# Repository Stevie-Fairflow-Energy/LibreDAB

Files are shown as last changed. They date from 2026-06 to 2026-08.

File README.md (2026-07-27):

# LibreDAB
An open source bi-directional Dual Active Bridge converter for connecting a Sodium Ion Battery to a 400 V DC link
Taking strong inspiration from the OwnTech microinverter: https://github.com/owntech-foundation/micro-inverter/

  Development Stage - Planning - Design has not started.

- **Manifesto**
	- The project goals are to:
		- Develop an open source bi-directional Dual Active Bridge converter for connecting a Sodium Ion Battery to a 400 V DC link.
		- Make the design repairable in itself.
		- Make the design a useful module within the context of solar PV, batteries and inverters. (e.g. a portable power station)
- **Open, for everyone, forever**
	- This project welcomes community input. With strong links to the OwnTech foundation and Fairflow Energy.
	- The collective work generated is meant to remain open.
	- Design files are made with open source software - Namely KiCAD.
- **Specifications**

Category | Requirement | Notes 
:---|:---|:---
Battery chemistry | Sodium Ion | New battery technology with abundant raw material availability 
Battery voltage range | 23.8 V - 58.8 V | 14 Series Cells of ~1.7 V to 4.2 V per cell. This enables compatibility with LibreSolar BMS C1 which sets a maximum voltage of 60 V. (https://github.com/LibreSolar/bms-c1) 
Nominal Battery Voltage | 42 V | Based on 3 V per cell 
Nominal Battery Current | 20 A | At 42 V and 800 W power transfer to DC link 
Peak Battery Current | 35.3 A | At 23.8 V and 800 W power transfer to DC link 
DC Link Voltage | 400 V | Based on a 230 V AC inverter 
Nominal DC link current | 2 A | 
Rated DC link Power | 800 W | Sufficient for a plug-in solar and storage application 
Efficiency | >95% | Target at nominal conditions 
Size | Target 70 mm x 280 mm PCB footprint | Similar size to 14 x 18650 cells next to each other 

- **Repairability**
	- Golden rules:
		- Components only placed on a single side of the PCB to allow simple rework
		- Components should be handle-able with standard tweezers (no smaller than 0402 packages)
		- Physical mounting is done with screws or other re-mountable arrangements
		- No invasive potting to enable inspection and service
		- There shall be test points available for all major power and control nets
	- Preferences:
		- Use of pin-compatible parts. e.g. a common footprint that has multiple options from different manufacturers to meet the same function
		- Minimise the number of different passive components used. e.g. parallel or series common components on the BOM where possible.
	- Notes:
		- Long-term relevance will be maintained at a whole module level. I.e. This DAB should be maintained and updated as a functional block when components used become unavailable. The physical size, mounting arrangements and connections should be maintained in future revisions.
	  
- **Control**
	- LibreDAB shall follow a bi-directional power reference. Therefore it needs to know voltage and current on both sides of the converter.
	- The reference can be delivered either as an analogue voltage signal or via serial.
	- LibreDAB shall provide a "No Error" indication, the absence of that indication should be read as an error.
   
- **Key Component Selections**
	- <100 V switch
		- TI LMG5200MOFR - 80 V, 10 A half bridge with driver
		- EPC2152 - 80 V, 15 A half bridge with driver
		- EPC23102 - 100 V, 35 A half bridge with driver - https://epc-co.com/epc/products/gan-fets-and-ics/epc23102
		- **Siliup SP010N01BGHTO 100 V 370A TOLL-8L MOSFET  https://www.lcsc.com/product-detail/C22385350.html?s_z=n_q_SP010N01BGHTO plus TI Driver UCC27211DDAR https://www.lcsc.com/product-detail/C141980.html?s_z=n_q_UCC27211DDAR**
	- . >500 V switch
		- **TI LMG2652 GaN Integrated Half Bridge and driver** 650 V, 140 mOhm - https://www.ti.com/product/LMG2652
		- Tokmas CID12N65D(TOKMAS) GaN single switch with integrated driver 650 V,  - 140 mOhm https://www.lcsc.com/product-detail/C21547657.html?s_z=n_q_C21547657&globalKeyword=C21547657
	- Controller
		- OwnTech SPIN https://www.owntech.org/spin-2/

- **Expected PCB Stackup**
	- 4 Layer FR4 insulated PCB with the following layer assignments:
		- Sig / Power 2oz
		- In.1 reference 2oz GND plane
		- Core
		- In.2 reference 2oz GND plane
		- Sig / Power 2oz
 - **Prototyping Status**
    - Prototype LV Bridge module ready for review.
    - Design in KiCAD 9.0.7
    - The LV Bridge module is a functional LV H bridge inverter to interface between the battery / BMS and the High Frequency DAB transformer. The prototype module has gate drivers on board as well as DC voltage and current measurements. The control interfaces for the gate drive signals, voltage and current measurements and 12 V and 5 V power supplies should be connected using 2.54 mm pin headers.
        - 4 Layer FR4 insulated PCB with the following layer assignments, with via stitching for power nets to maximise use of the PCB copper for power transfer:
		  - Sig / Power 1oz
		  - In.1 reference 0.5oz GND plane
		  - Core
		  - In.2 reference 0.5oz GND plane
		  - Sig / Power 1oz
    - Specifications for LV Bridge prototype module:
    
Category | Requirement | Notes 
:---|:---|:---
Battery voltage range | 23.8 V - 58.8 V | 14 Series Cells of ~1.7 V to 4.2 V per cell. This enables compatibility with LibreSolar BMS C1 which sets a maximum voltage of 60 V. (https://github.com/LibreSolar/bms-c1) 
Nominal Battery Voltage | 42 V | Based on 3 V per cell 
Nominal Battery Current | 20 A | At 42 V and 800 W power transfer to DC link 
Peak Battery Current | 35.3 A | At 23.8 V and 800 W power transfer to DC link 
Efficiency | >97% | Target at nominal conditions 
Size | 92 mm x 92 mm PCB  | Sized to mount 92 mm fan

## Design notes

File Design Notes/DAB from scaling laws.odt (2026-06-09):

Designing a DAB using Scaling Laws

Reference: https://ridleyengineering.com/images/webinar/DAB_Design_Using_Scaling_Laws.pdf

Aims:

LV stage:

Vnom = 42 V

Vmin = 23.8 V

Vmax = 58.8 V

Pnominal = 800 W

Imax = 35.3 A

HV stage:

Vnom = 400 V

Vmax = 420 V

Vmin = 360 V

Pnominal = 800 W

Imax = 2.22 A

Fsw starting point = 1000 kHz

Choose a Single Phase Shift mode

I.e. (Intra bridge) Angle 1 = 180 °

(Inter bridge) Angle 2 = Control angle up to 45 °

Gain = 1

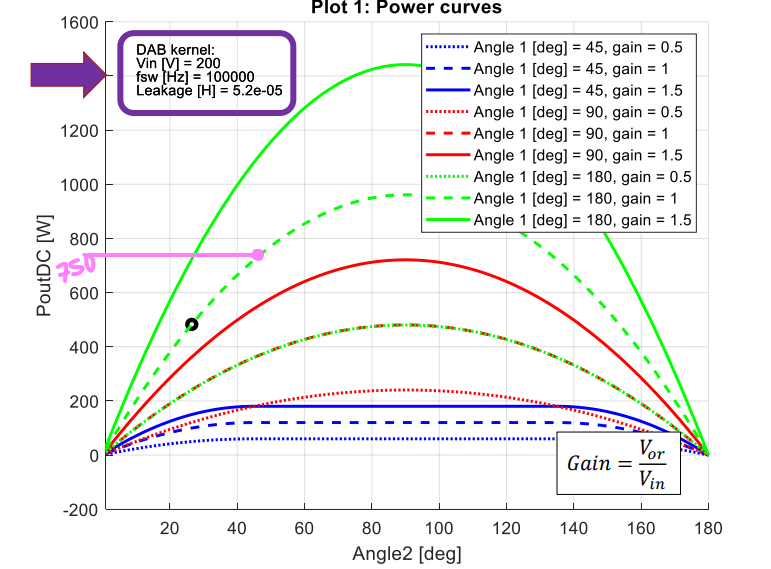
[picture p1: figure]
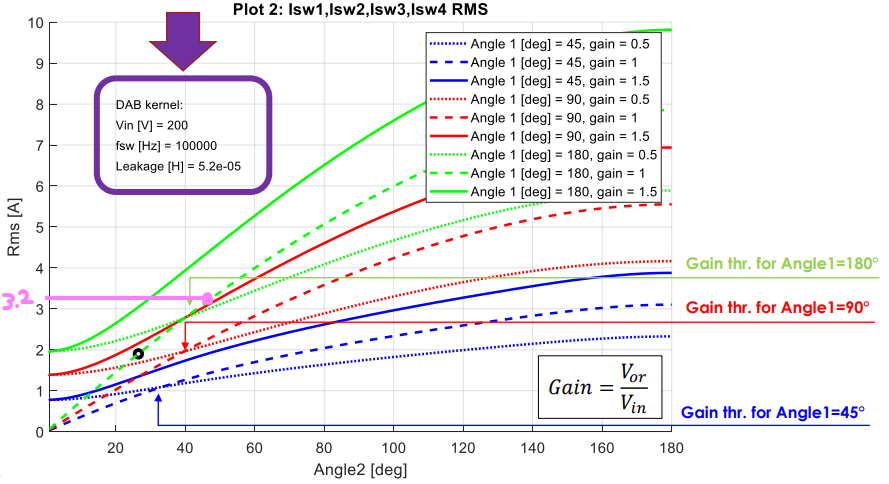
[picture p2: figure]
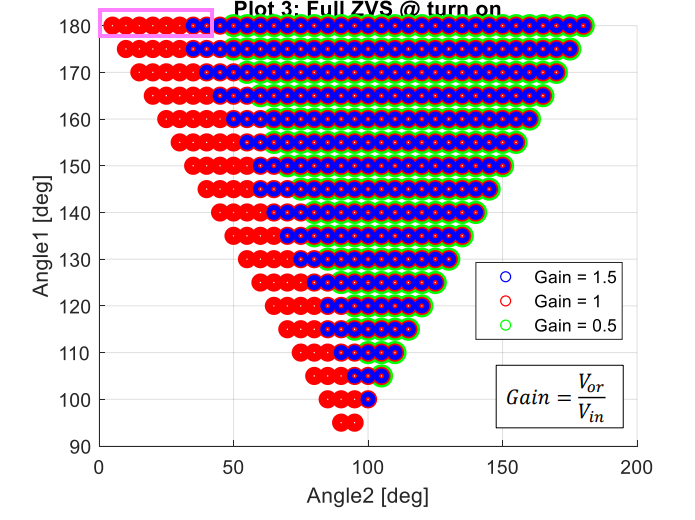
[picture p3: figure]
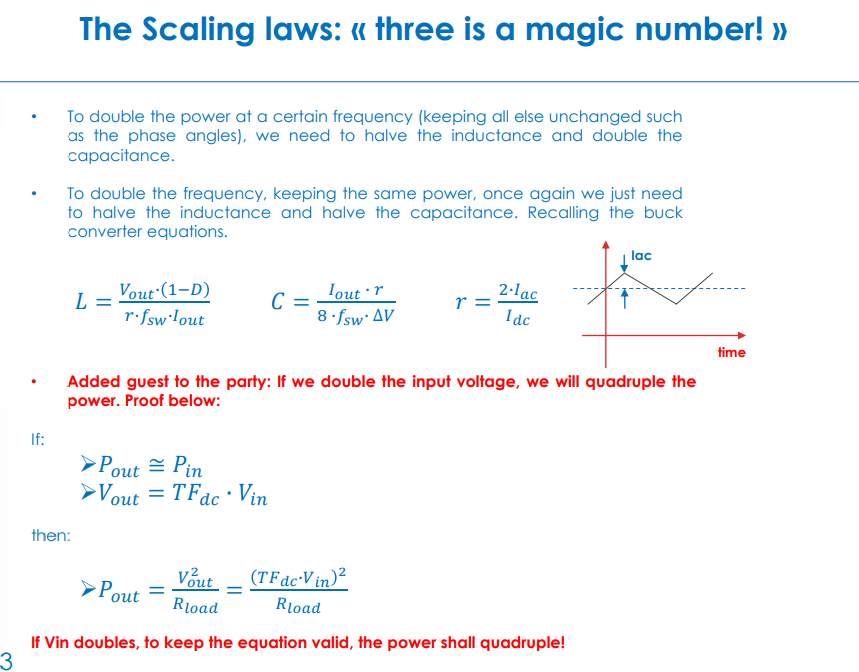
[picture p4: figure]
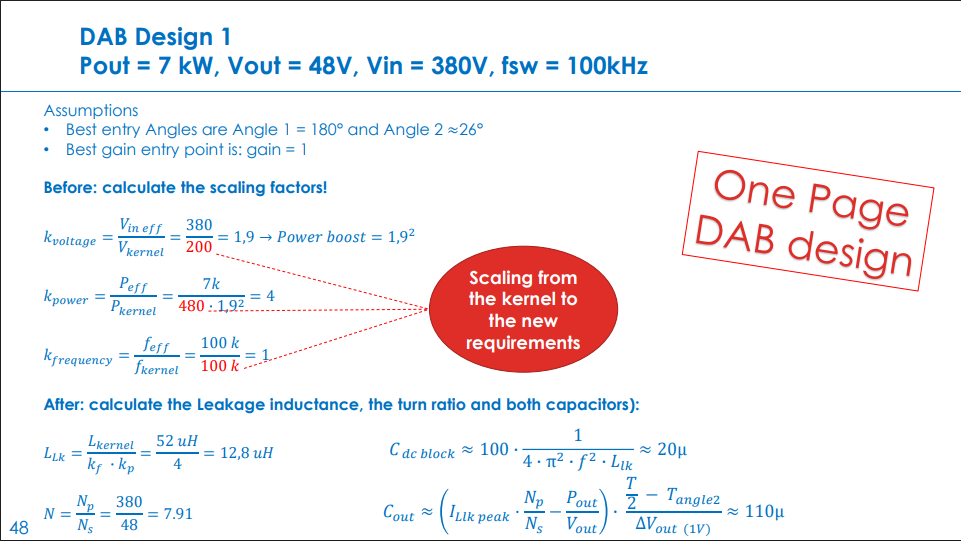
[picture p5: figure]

Kernel power: 1050 W (Angle 1 = 180 °, Angle 2 = 45 °, Gain = 1.5)

Kernel Fsw = 100 kHz

Kernel Leakage = 5.2e-05 H

Kernel Input voltage: 200 V

I_Llk_peak = 10 A

Aims:

LV stage:

Vnom = 42 V

Vmin = 23.8 V

Vmax = 58.8 V

Pnominal = 800 W

Imax = 35.3 A

To cope with the high voltage input range, we need to make use of the non linear DAB characteristics.

We want to operate the DAB at 1.5 gain, Angle2 at 60 degrees, at the lowest part of the voltage range.

This results in a L_lk of ~115 nH and a C_dcblock of ~22 uF.

How practical is a L_lk of 115 nH?

HV stage:

Vnom = 400 V

Vmax = 420 V

Vmin = 360 V

Pnominal = 800 W

Imax = 2.22 A

Fsw starting point = 1000 kHz

T = 1 / 1000 kHz = 1 us

Tangle2 = 0.125*T = 0.125 us

Choose a Single Phase Shift mode

I.e. (Intra bridge) Angle 1 = 180 °

(Inter bridge) Angle 2 = Control angle up to 45 °

Gain = 1

k_voltage = Vin_eff / Vkernel = 42 / 200 = 0.21 -> Power “boost” 0.24^2 = 0.00441

k_power = Peff / Pkernel = 800 / (750*0.21^2) = 24.187

k_frequency = f_eff / f_kernel = 1000 k / 100 k = 10

L_lk = Lkernel / (k_frequency x k_power) = 52 uH / (10*24.187) = 0.215 uH

C_dcblock = 100 x ( 1 / (4 x pi^2 x f^2 x L_lk) = 12 uF

N = Np / Ns = 42 / 400 = 0.105

CHECK FROM HERE

I_Llk_peak = (I_Llk_peak_kernel * k_voltage) * (Peff / Pkernel) = (10 * 0.24) / (5000 / 750) = 277.77 A

Cout = (I_Llk_peak * (N - Pout / Vout)) * ( (T/2 - Tangle2) / deltaVout) = (277.77 * 0.114 - 5000/420) * ( (10u/2 - 1.25u) / 1) = 105 uF

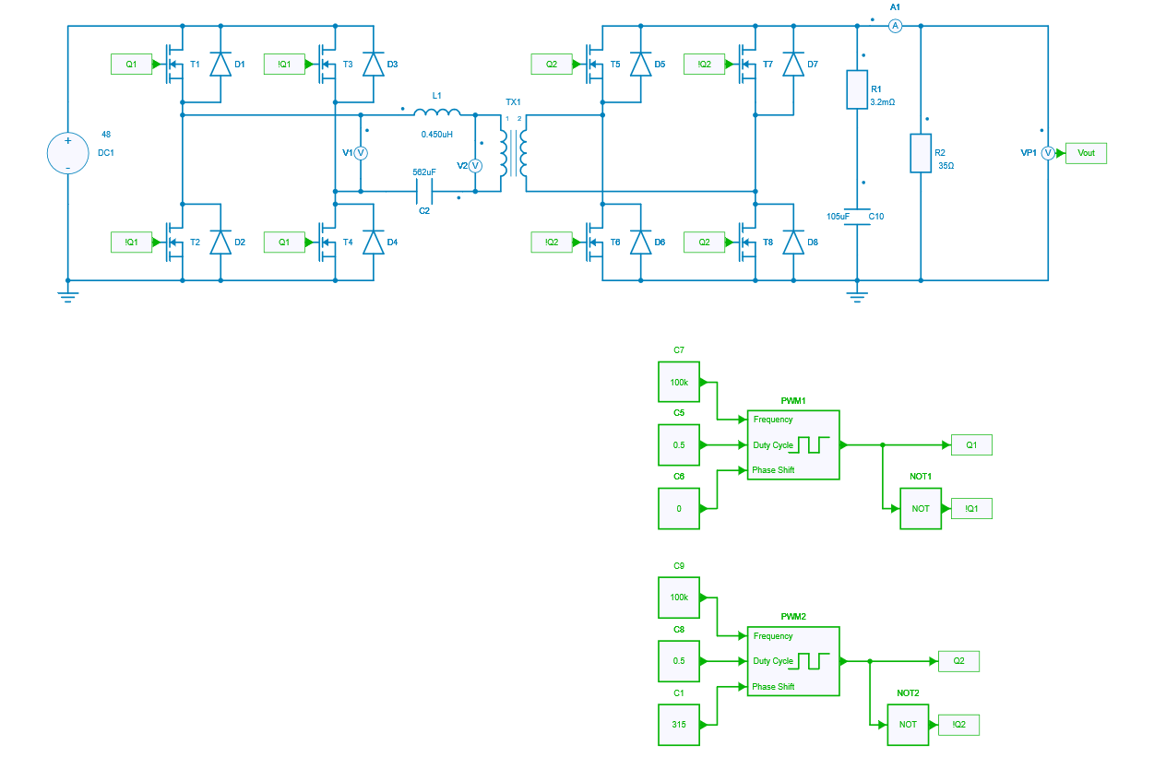
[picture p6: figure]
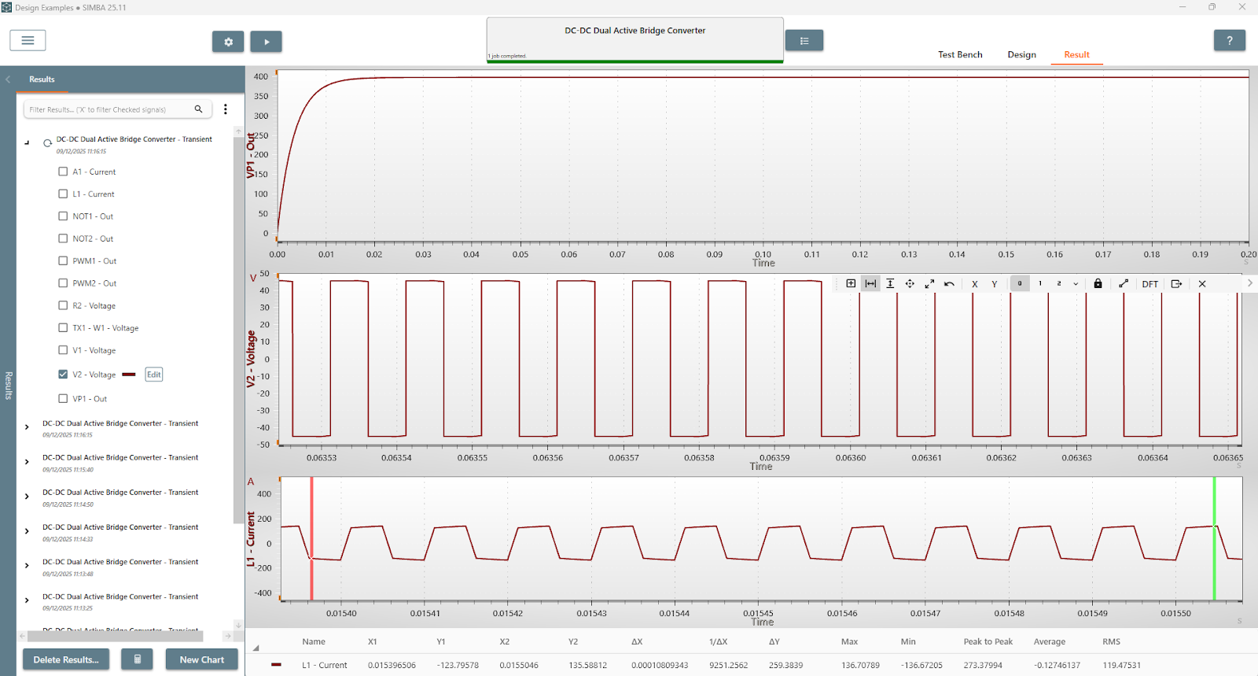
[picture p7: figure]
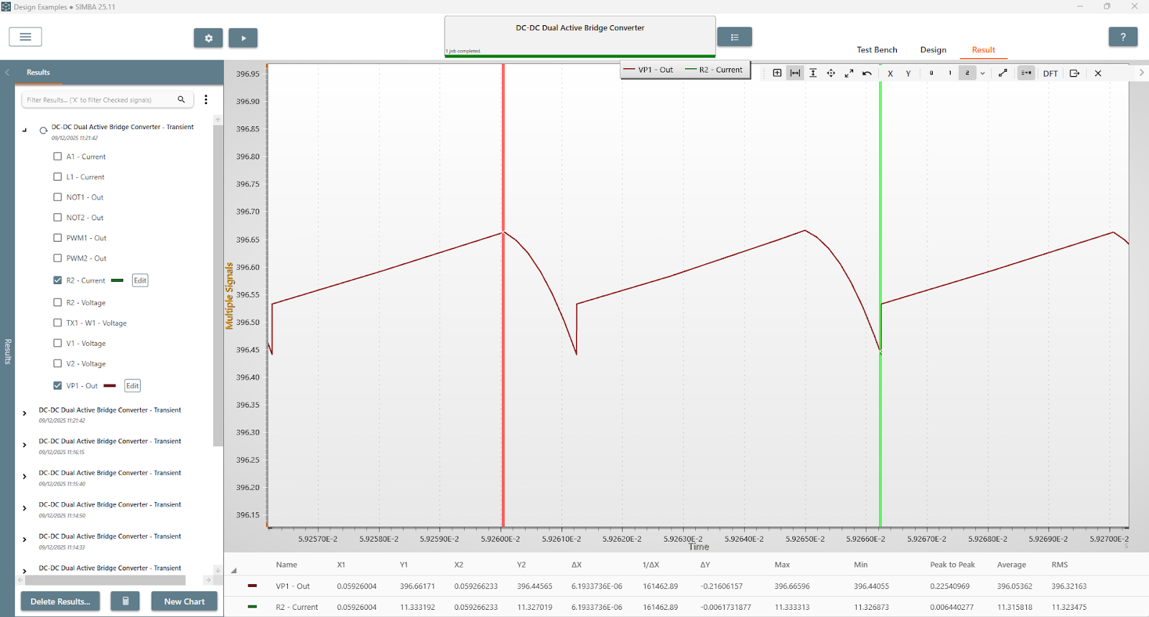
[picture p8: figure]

Validation:

396 V on 200 Ohm resistor -> P = V^2 / R = (396^2) / 35 = 4480.457 W

Note that 50 mOhm Rds_on MOSFETs resulted in a significant voltage drop. Changed to 5 mOhm and this is the result.

Voltage ripple ~ 0.2 V

Input into openmagnetics:

Core: https://uk.rs-online.com/web/p/transformer-cores/6479389

Coil former: https://uk.rs-online.com/web/p/transformer-accessories/1253682

Windings:https://www.rmcybernetics.com/shop/wire-cable/litz-wire

“40A” and “6A” variants for primary and secondary respectively. Should be possible to wind to get ~450 nH leakage

Costs:

- Core = £18.54
- Primary wire (1 m) = £18
- Secondary wire (10m) = £38
- Coil former = £10
- Total ~ £85

Ranges from 293 nH to 1300 nH depending on winding arrangement.

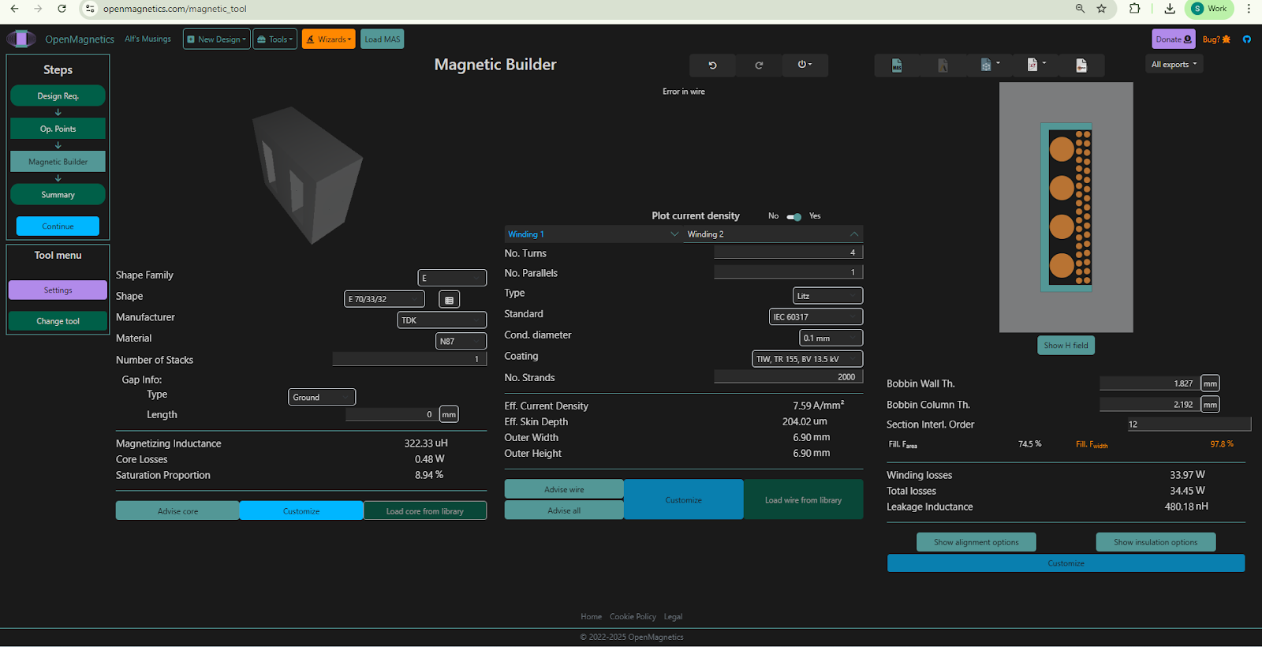
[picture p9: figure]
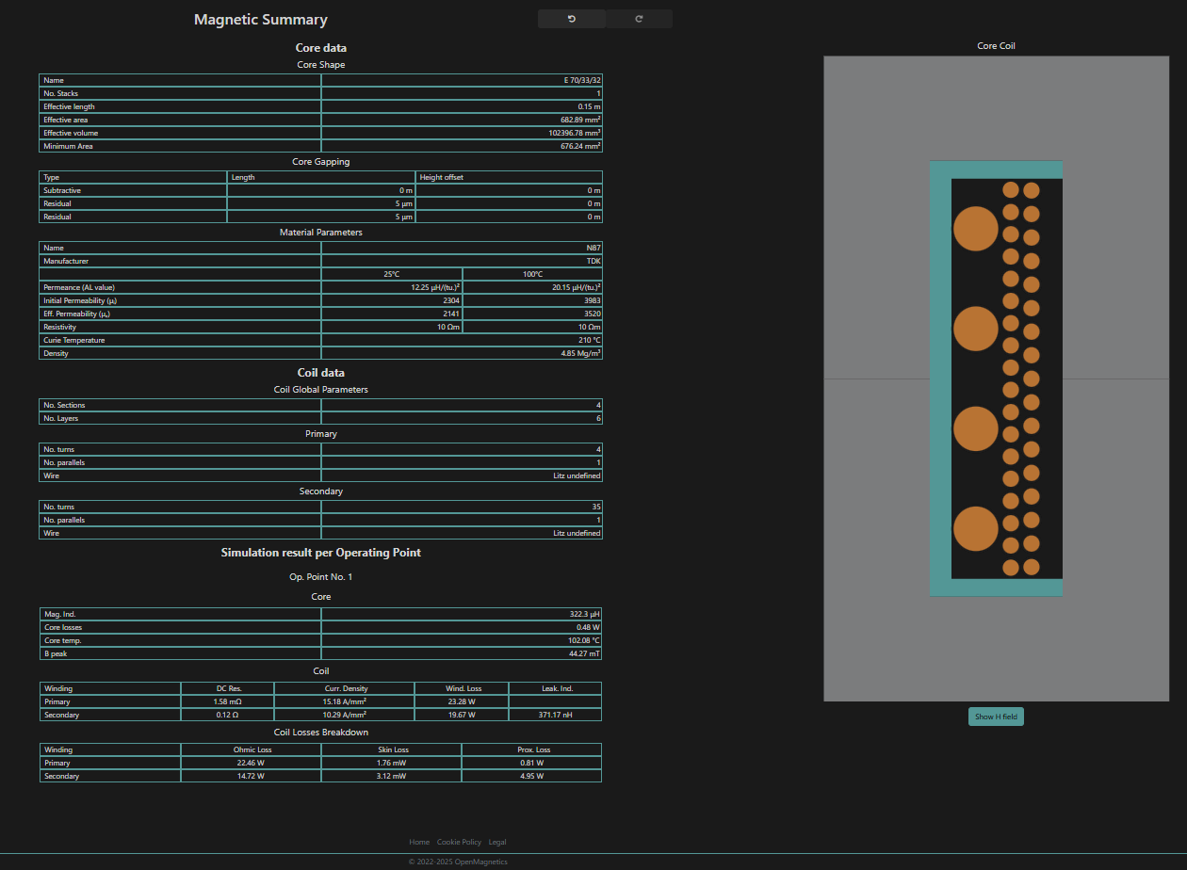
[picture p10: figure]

Approximately 44 W of losses to deal with on the E type design.

# Magnetics iterations

Tried out both a Toroidal core and an ETD core.

The toroidal core option came in at low cost and low loss. 1.7 W core loss, 26 W of winding losses. BUT the winding and mounting arrangements required extra consideration. There was no off-the-shelf mount for the toroid and with Litz wire it wouldn’t be self-supporting.

So the ETD option comes in with ~22 W of total losses after adjusting the number of windings slightly and the size of the secondary Litz wire. It’s likely the losses of the other variants could have been reduced to these levels with some tweaking.

Litz vs non-Litz. At 100 kHz and these current levels, the difference between Litz and standard wires was significant! It made 10’s of Watts of loss difference for similar size wires. Likely to cause some serious overheating problems, as well as the efficiency hit!

The plus side of using the ETD core (ETD 59/31/22) is also that you can buy an off-the-shelf winder and yoke (to clip the core to the winder). This is useful because it gives a really nice mounting arrangement that lets you directly insert the transformer into a PCB or connect up with wires for testing.

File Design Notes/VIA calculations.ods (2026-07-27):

Holes per metre^2 | 100000
Holes per cm^2 | 10
Holes per mm^2 | 0.1
Spacing of holes (mm) | 3.16227766016838
92 mm x 92 mm board, how many vias
Board width (mm) | 92
Board length (mm) | 92
Board area (mm^2) | 8464
Spacing of holes (mm) | 3
Vias in x direction | 30.6666666666667
Vias in y direction | 30.6666666666667
Total vias | 940.444444444445
Vias per mm^2 | 0.111111111111111
Source of 100000 “limit” | https://jlcpcb.com/help/article/in-what-cases-will-there-be-charged-extra

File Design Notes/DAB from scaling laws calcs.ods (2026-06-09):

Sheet: Sheet1
Kernel
Power (W) | 1250
Fsw (Hz) | 100.00E+03
Leakage (H) | 52.00E-06
Input Voltage | 200
I_Llk_peak | 10
Angle1 | 180
Angle2 | 60
Gain | 1.5
Design aims:
Power (W) | 800
Gain | 1.5
Angle1 | 180
Angle2 | 60
LV stage
Target efficiency (%) | 95.00%
Vnom (V) | 23.8
Vmin (V) | 23.8
Vmax (V) | 58.8
Imax (A) | 35.2941176470588
HV stage
Vnom (V) | 400
Vmax (V) | 420
Vmin (V) | 360
Imax (A) | 2.33333333333333
Fsw (Hz) | 5.00E+05
T (s) | 2.00E-06
Tangle2 (s) | 333.33E-09
k_voltage | 0.014161
k_power | 45.1945484075983
k_frequency | 5
L_lk (H) | 230.12E-09
C_dcblock (F) | 44.03E-06
N | 0.08925 | 11.2044817927171
I_Llk_peak | 34.4753285929756 | A consistent underestimate
Design:
N (N2/N1) | 9
L_lk (H) | 230.12E-09
Power (W) | 800
Gain | 1
Fsw (Hz) | 2.00E-06
I_Llk_peak

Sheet: Transformer
 | Primary | Secondary
Turns | 1 | 11
Parallel | 2 | 1
Type | Litz | Litz
RMCybernetics Standard | 12 A | 3 A
Strand size (AWG) | 44.0398272808926 | 41.1377859747528
Strand size (mm) | 0.05 | 0.07
Number of strands | 1000 | 160
Core | RM12 | RM12 | https://uk.farnell.com/epcos/b65815e0000r049/transformer-core-rm-n49-57mm/dp/4167325

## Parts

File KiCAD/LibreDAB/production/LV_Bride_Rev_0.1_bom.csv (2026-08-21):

Designator | Footprint | Quantity | Value | LCSC Part #
C1, C11, C3, C7, C9 | C3861036_C0805 | 5 | 4.7uF 50V X7S 0805 | C3861036
C10, C8 | C176292_C0805 | 2 | 20pF 50V C0G 0805 | C176292
C12, C2 | C5182461_C0805 | 2 | 100nF 250V X7R 0805 | C5182461
C13 | C41582415_C1206 | 1 | 4.7uF ±10% 100V | C41582415
C4 | C3031594_CAP-SMD_BD10_0-L10_3-W10_3-FD | 1 | 47uF, 100 V | C3031594
C5, C6 | C46653_C0805 | 2 | 1nF (102) ±10% 50V | C46653
D1 | C49066953_SMB_L4_5-W3_7-LS5_4-RD | 1 | TVS DIODE 60VWM 96.8VC SMB(DO-214AA) | C49066953
H1, H2, H3, H4 | MountingHole_4.3mm_M4_DIN965_Pad | 4 | MountingHole_Pad | C2916333
J1, J4, J5, J6 | C48641754_HDR-SMD_4P-P2_54-V-F-LS4_7-R1 | 4 | HX PM2.54-1X4P TP H8.5-ZQ | C48641754
J2, J3, J7, J8 | C51018168_SMD_L5_0-W5_0_CON1_5X5_SMD | 4 | TS30050050-040 | C51018168
LOGO1 | FFE_Logo_12x12mm_Silk | 1 | N/A
Q1, Q2, Q3, Q4 | C22385350_TOLL-8_L10_4-W9_9-P1_20-LS11_7-BL_2 | 4 | SP010N01BGHTO | C22385350
R1 | C2989281_R0805 | 1 | 47kΩ ±0.1% 125mW 0805 | C2989281
R10, R11, R16, R17 | C2907219_R0805 | 4 | 10kΩ ±1% 0805 | C2907219
R12, R13 | C865408_R0805 | 2 | 330kΩ ±0.1% 125mW 0805 | C865408
R14, R15, R8, R9 | C393074_RES-SMD_L6_4-W3_2-1 | 4 | 3.3Ω ±5% 1W 2512 | C393074
R2 | C2989281_R0805 | 1 | 12.1kΩ_±0.1%_125mW_0805 | C2989281
R3 | C309662_R1206 | 1 | 1MΩ ±0.1% | C309662
R4 | C865332_R0805 | 1 | 25.5kΩ ±0.1% | C865332
R5 | C710260_RES-SMD_L6_4-W3_2_RLM25 | 1 | 0.5mΩ ±1% 3W 2512 | C710260
R6, R7 | C7431042_R0805 | 2 | 10kΩ ±0.1% 125mW 0805 | C7431042
TP1, TP10, TP11, TP12, TP13, TP14, TP15, TP16, TP17, TP18, TP19, TP2, TP20, TP21, TP3, TP4, TP5, TP6, TP7, TP8, TP9 | TestPoint_Pad_D1.0mm | 21 | TestPoint_Probe
U1, U5 | C141980_SOIC-8_L4_9-W3_9-P1_27-LS6_0-BL-EP | 2 | UCC27211DDAR | C141980
U2, U3, U4 | C398358_SOT-23-5_L3_0-W1_7-P0_95-LS2_8-BL | 3 | 10 MHz Opamp | C398358

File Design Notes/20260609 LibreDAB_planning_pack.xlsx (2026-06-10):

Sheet: README
LibreDAB — Planning Pack (block diagram, BOM, size & risk)
Open-source GaN, 1 MHz Dual Active Bridge — Sodium-Ion battery <-> 400 V DC link, 800 W
Status | Planning stage. Figures are first-pass estimates to be confirmed in detailed design + prototype.
Prepared | Initial pass, June 2026
Locked decisions | Full-bridge both sides; SPIN as plug-in controller; series L from transformer leakage; cooling sized from thermals.
Confidence legend | H = high (datasheet/quote), M = medium (engineering estimate), L = low (rough / needs prototype)
Colour legend | Blue cells = inputs you can change. Black = calculated/text. Yellow = key assumption.
FX assumption | GBP per USD used for converting USD-quoted parts (see Cost_Summary, change in one place).
Sheets
Design_Calcs | DAB operating points, required series inductance, transformer flux density & leakage feasibility.
Loss_Thermal | Loss budget at nominal and worst-case corner; efficiency; cooling recommendation.
BOM | Line-by-line bill of materials with sources (LCSC / UK-custom / off-LCSC), costs and references.
Cost_Summary | Roll-up by category, per-board total and low/high range.
Size_Estimate | Area budget against the 70 x 280 mm single-sided board; Z-height note.
Risk_Register | Ranked risks with likelihood x impact and mitigations.
References | All sources with URLs (every checkable figure is traceable here).
IMPORTANT | GaN power devices (LMG2100R026, LMG2652) are NOT in the LCSC catalogue. They are off-LCSC lines
 | (Mouser/DigiKey/TI) - now an all-TI power stage (single vendor). All-LCSC HV fallback (Tokmas CID12N65D x4 + drivers) noted in BOM.

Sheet: Design_Calcs
DAB Design Calculations (single-phase-shift model)
Topology assumption: full bridge both sides, battery = primary (1T), DC link = secondary (11T)
Inputs (blue = change)
Battery nominal voltage | 42.0 | V
Battery minimum voltage | 23.8 | V
Battery maximum voltage | 58.8 | V
DC link voltage | 400 | V
Rated power | 800 | W
Switching frequency | 1000000 | Hz
Turns ratio n = Ns/Np | 11 | -
Primary turns Np | 1 | -
Core A_L (assembled pair) | 3.7e-06 | H
Core effective area Ae | 0.000146 | m^2
Design phase shift (nominal) | 50 | deg
Assumed efficiency (for current calc) | 0.95 | -
Primary RMS factor (x I_dc, rough) | 1.2 | -
Calculations
Secondary turns Ns | 11 | -
Reflected link voltage to primary (Vlink/n) | 36.4 | V
Battery current at nominal | 19.0 | A
Battery current at min V (incl. eff.) | 35.4 | A
Phase shift (radians) | 0.873 | rad
Phase shape factor φ(1-φ/π) | 0.630 | -
REQUIRED series inductance, referred to primary | 1.914983165e-07 | H
= required series inductance (primary) | 191.4983165 | nH
= required series inductance (secondary) | 23.2 | uH
Magnetizing inductance (primary) | 3.7e-06 | H
Required leakage as % of magnetizing | 5.2% | %
Peak flux density (secondary, square-wave approx) | 0.062 | T
= peak flux density (secondary) | 62.26650062 | mT
Peak flux density (primary, approx) | 71.91780822 | mT
Primary RMS current at nominal | 22.9 | A
Primary RMS current at min-V corner | 42.5 | A
Interpretation
Required leakage (~5% of magnetizing) is HIGH for a tightly-coupled RM transformer (typical 1-3%).
Achieving AND controlling this with a single-turn primary is the dominant magnetics risk (see Risk M-01).
Flux density ~60-72 mT at 1 MHz in N49 is acceptable but core loss is non-trivial (see Loss_Thermal).
Battery range 23.8-58.8 V is a 2.47:1 swing -> reflected 262-647 V vs fixed 400 V link; ZVS range and RMS
currents vary strongly with state-of-charge. Adaptive modulation likely needed (Risk C-01).
Required series L scales with design phase shift (blue input row 15); lower phase shift -> lower L needed.

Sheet: Loss_Thermal
Loss Budget & Thermal Recommendation
Efficiency target >95% at NOMINAL (42 V, 800 W). Worst case = 23.8 V / full power.
Block | Loss @ nominal (W) | Loss @ worst corner (W) | Confidence | Basis / source
LV full bridge (2x LMG2100R026, 2.6 mΩ) | 5 | 11 | M | Lower Rds (2.6 mΩ) cuts conduction; 53 A rating eases low-V corner
HV full bridge (2x LMG2652, 140 mΩ) | 5 | 7 | M | Low HV current; 650 V ZVS switching dominates at 1 MHz
HF transformer (core + copper) | 4 | 6 | M | N49 ~60-72 mT @1 MHz; user est 2 W is optimistic
Bias / gate drive / control | 2 | 3 | M | Gate charge x f, aux supply, sensing
PCB / interconnect / connectors | 2 | 4 | L | I^2R in copper at 19-35 A on LV side
TOTAL LOSS | 18 | 31
Output power (W) | 800
Estimated efficiency | 97.8% | 96.3%
Cooling recommendation (sized from thermals)
Worst-case ~40 W (low-SoC, full power) over a 70x280 mm (196 cm^2) single-sided board.
Natural convection alone (~10-20 W at acceptable rise) is INSUFFICIENT at the worst corner.
RECOMMENDED: conduction to a chassis/baseplate as the main heat path, plus a screw-mounted
top-side heatsink bar over the LV stage (EPC23102 has an exposed-TOP cooling pad - ideal, removable).
HV stage (LMG2652) is bottom-cooled: thermal vias to a bottom plane -> gap pad -> chassis.
Provide footprint/headers for an optional small fan for continuous worst-corner operation.
This satisfies the repairability rules: single-sided placement, screwed (not potted) heatsinks.

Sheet: BOM
Bill of Materials (per board, low-volume / prototype pricing)
Sources: LCSC (PCBway-orderable) unless noted UK-custom or off-LCSC. Costs in GBP.
# | Block | Function / Ref | Part number | Mfr | Source | Qty | Unit £ | Ext £ | Quoted price (native) | Datasheet / link | Conf. | Notes
1 | LV bridge | HS+LS GaN half-bridge x2 (full bridge) | LMG2100R026 | TI | off-LCSC (Mouser/DigiKey) | 2 | £8.00 | £16.00 | ~$8-13 low qty; in stock | https://www.ti.com/product/LMG2100R026 | M | 93V cont/100V pulsed, 53A, 2.6 mOhm, top-cooled. All-TI w/ HV. NOT on LCSC
2 | HV bridge | HV GaN half-bridge x2 (full bridge) | LMG2652RFBR | TI | off-LCSC (Mouser/DigiKey) | 0 | £6.00 | £0.00 | ~$7-8; 12-wk lead | https://www.ti.com/product/LMG2652 | M | Integrated driver+current sense; bottom-cooled; 12-wk lead
3 | HV bridge (ALT) | All-LCSC HV fallback: single switch x4 + drivers | CID12N65D | Tokmas | LCSC C21547657 | 4 | £0.50 | £2.00 | $0.6276 LCSC | https://www.lcsc.com/product-detail/C21547657.html | M | Alternative path: needs 4 x modules instead of 2 x
4 | Magnetics | RM12 core set (N49) | B65815E0000R049 | TDK/EPCOS | UK (Farnell/TME) - custom | 1 | £8.00 | £8.00 | ~£6-12/pair | https://uk.farnell.com/epcos/b65815e0000r049/transformer-core-rm-n49-57mm/dp/4167325 | M | A_L 3700 nH, Ae 146 mm^2, sold as pair
5 | Magnetics | RM12 coil former (bobbin) + clips | RM12 bobbin/clip set | TDK/EPCOS | UK - custom | 1 | £4.00 | £4.00 | ~£3-5 | https://www.tdk-electronics.tdk.com/inf/80/db/fer/rm_12.pdf | M | Required to wind transformer
6 | Magnetics | Litz wire (primary heavy + secondary) | Litz 12A & 3A | RM Cybernetics | UK - custom | 1 | £15.00 | £15.00 | ~£10-25 | https://www.rmcybernetics.com/ | L | Single-turn primary at ~40 A RMS may need paralleled bundles
7 | Magnetics | Transformer winding / assembly (custom labour) | Custom wound RM12 | UK winder | UK - custom | 1 | £25.00 | £25.00 | ~£15-50 | https://www.rmcybernetics.com/ | L | Leakage must be tuned & measured; biggest cost uncertainty
8 | HV cap | DC-link bus capacitance (C0G/film, 500-630 V) | ceramic/film array | various | LCSC | 1 | £8.00 | £8.00 | allowance | https://www.lcsc.com/ | M | High-freq bus decoupling near HV bridge
9 | LV cap | Battery-side bulk + decoupling (high ripple) | ceramic + polymer | various | LCSC | 1 | £8.00 | £8.00 | allowance | https://www.lcsc.com/ | M | Ripple current rating critical at 1 MHz / 35 A
10 | Sensing | Battery current sense (shunt + isolated amp or Hall) | e.g. TMCS/INA-class | various | LCSC | 1 | £5.00 | £5.00 | allowance | https://www.lcsc.com/ | M | HV current available from LMG2652 integrated sense
11 | Sensing | Voltage dividers + scaling buffer (both sides, 0-2.048 V) | resistors + op-amp | various | LCSC | 1 | £3.00 | £3.00 | allowance | https://www.lcsc.com/ | M | Conditioned to SPIN ADC 0-2.048 V range
12 | Bias | Aux/isolated supply + LDOs (5 V / VDD rails) | iso DC-DC + LDO | various | LCSC | 1 | £6.00 | £6.00 | allowance | https://www.lcsc.com/ | M | Powers GaN gate-driver bias on both domains
13 | Interface | Battery connector (35 A rated) | screw terminal / high-current | various | LCSC | 1 | £4.00 | £4.00 | allowance | https://www.lcsc.com/ | M | Repairable, re-mountable per golden rules
14 | Interface | 400 V link connector | >600 V rated | various | LCSC | 1 | £3.00 | £3.00 | allowance | https://www.lcsc.com/ | M
15 | Interface | SPIN header (2.54 mm) | pin header | various | LCSC | 1 | £2.00 | £2.00 | allowance | https://www.owntech.org/spin-2/ | H | PWM out + ADC in (0-2.048 V) + serial/analog ref
16 | Interface | Test points (all major nets) | SMD test points | various | LCSC | 1 | £2.00 | £2.00 | allowance | https://www.lcsc.com/ | H | Golden rule: TPs on all major power & control nets
17 | Indicator | 'No Error' status LED + driver | LED + transistor | various | LCSC | 1 | £1.00 | £1.00 | allowance | https://www.lcsc.com/ | H | Absence of indication = error
18 | Passives | Gate Rs, bootstrap caps, decouplers, dividers | 0402/0603 passives | various | LCSC | 1 | £5.00 | £5.00 | allowance | https://www.lcsc.com/ | M | Min. part diversity per golden rules
19 | Thermal | Top-side heatsink (LV) + TIM + screws | heatsink+pad | various | UK/LCSC | 1 | £6.00 | £6.00 | ~£4-10 | https://www.lcsc.com/ | L | Screw-mounted, removable
20 | PCB | 4-layer 2 oz, 70 x 280 mm (qty 5 amortised) | custom PCB | PCBway | PCBway | 1 | £20.00 | £20.00 | ~£12-35/board | https://www.pcbway.com/orderonline.aspx | L | 2 oz copper + large area push cost up; use PCBway calculator
 |  |  |  |  |  |  | PER-BOARD TOTAL | £143.00
 | Note: ALT row (Tokmas) qty set to 0 so it is excluded from the total; switch quantities to swap the HV path.

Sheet: Cost_Summary
Cost Summary (per board)
FX assumption: GBP per USD | 0.79 | (=1/1.27; used where parts quoted in USD)
Category | Cost £ | Confidence | Comment
Semiconductors (GaN) | £16.00 | M | LMG2100R026 x2 + LMG2652 x2; all-TI, off-LCSC
Magnetics (custom, UK) | £52.00 | L | Core+bobbin+litz+winding; dominant uncertainty
Capacitors | £16.00 | M | HV bus + LV bulk/decoupling
Sensing & control interface | £26.00 | M | Current/voltage sense, bias, connectors, TPs, LED
Misc passives | £5.00 | M | Gate Rs, bootstrap, dividers
Thermal | £6.00 | L | Heatsink + TIM
PCB (PCBway) | £20.00 | L | 4-layer 2 oz, 70x280 mm
POINT-ESTIMATE TOTAL | £141.00
Range factors (blue)
Low factor | 0.75
High factor | 1.55
Estimated low (£) | £105.75
Estimated high (£) | £218.55
Overall cost confidence: M-L. Drivers of spread: custom transformer, low-qty GaN pricing, PCB area/copper.

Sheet: Size_Estimate
Size Estimate vs 70 x 280 mm target
Board area available (single-sided) | 196 | cm^2 (=196)
Block | Approx area (cm^2) | Conf. | Notes (footprint basis)
LV full bridge + input caps | 22 | M | 2x LMG2100R026 (7x4.5 mm) + decoupling + heavy-copper pour
HV full bridge + bus caps | 22 | M | 2x LMG2652 (6x8 mm) + 400 V bus caps
HF transformer (RM12) | 18 | M | Core ~37.6x29.8 mm + clearance; tallest part ~25 mm
Sensing + bias + control interface | 25 | M | Dividers, current sense, aux supply, SPIN header
Connectors + test points | 18 | M | Battery (35 A) + 400 V link + TPs
Isolation barrier / creepage gap | 20 | M | 400 V <-> battery separation under/around transformer
Routing / margin | 35 | L | Spacing, vias, keep-outs, single-sided routing overhead
TOTAL allocated | 160
Spare vs 196 cm^2 | 36
Verdict: fits the 70x280 mm footprint with modest margin (conf M). Z-height is set by the RM12
core (~25 mm) plus the top-side heatsink, so the module depth - not PCB area - is the tighter constraint.

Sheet: Risk_Register
Risk Register
Likelihood (L) & Impact (I) on 1-5 scale; Score = L x I. Higher = attend first.
ID | Category | Risk | L | I | Score | Mitigation | Status
M-01 | Magnetics | Leakage-only series L (~5% of magnetizing, single-turn primary) hard to hit AND control; sets power transfer | 4 | 4 | 16 | Design winding separation for target leakage; measure & tune on prototype; keep discrete shim inductor as fallback | Open
T-01 | Thermal/Device | LV switch current at 23.8 V full-power corner (~42 A) vs 53 A rating -> comfortable margin; thermal still to manage | 2 | 3 | 6 | Top-side heatsink + conduction; verify 1 MHz thermal derating at worst corner | Open
S-01 | Sourcing | GaN power ICs not on LCSC (EPC23102) / LMG2652 12-wk lead -> not fully PCBway-assemblable | 4 | 3 | 12 | Dual-source; pre-order long-lead; all-LCSC Tokmas HV path; consign parts to PCBway | Open
L-01 | Layout/EMI | 1 MHz GaN gate loops, switching-node ringing, conducted/radiated EMI | 4 | 3 | 12 | Tight power-loop layout; follow EPC/TI ref designs; slew-rate control; input/output filtering | Open
I-01 | Isolation | 400 V <-> battery isolation incl. sensing & gate-drive references and PCB creepage | 3 | 4 | 12 | Define isolation standard; PCB creepage/clearance; isolated sense & bias across barrier | Open
C-01 | Control | Wide 2.47:1 battery range degrades ZVS range & raises RMS currents at SoC extremes | 3 | 3 | 9 | Adaptive modulation (extended-phase-shift / triangular) in SPIN firmware; verify ZVS map | Open
E-01 | Efficiency | Meeting >95% at 1 MHz once real core, AC-copper, gate & ringing losses are included | 3 | 3 | 9 | Refine loss model; optimise magnetics & ZVS; treat >95% as nominal-point target | Open
M-02 | Magnetics | Custom hand-wound transformer: cost, lead time and unit-to-unit repeatability | 3 | 3 | 9 | Document winding spec; qualify a UK winder; characterise L_leak & losses per unit | Open
P-01 | PCB | 35 A on LV side: copper heating, via current, thermal coupling to devices | 3 | 3 | 9 | 2 oz (or heavier) copper, large pours, paralleled layers, thermal vias | Open
R-01 | Repairability | GaN QFNs (incl. exposed-pad) are hard to hand-rework vs golden rules | 2 | 3 | 6 | Single-sided placement; hot-air-reworkable layout; spacing; full test points | Open
X-01 | Caps | LV bus ripple-current rating at 1 MHz / high current | 2 | 3 | 6 | Ceramic arrays with adequate ripple rating; verify thermals | Open
D-01 | Control/Spec | Bidirectional reference (analog OR serial) + 'no-error' logic complexity | 2 | 3 | 6 | Leverage OwnTech SPIN stack; staged firmware bring-up; clear fault state machine | Open

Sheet: References
References (all checkable)
# | Source | Supports | URL
1 | TI LMG2100R026 product page | LV GaN: 93 V cont/100 V pulsed, 53 A, 2.6 mΩ, integrated driver, top-cooled | https://www.ti.com/product/LMG2100R026
2 | TI LMG2100R026 datasheet (PDF) | Electrical specs, 7.0x4.5 mm 18-VQFN, UVLO/clamp protection | https://www.ti.com/lit/ds/symlink/lmg2100r026.pdf
3 | DigiKey LMG2100R026VBNR | Availability (in stock) & low-qty pricing - verify before order | https://www.digikey.com/en/products/detail/texas-instruments/LMG2100R026VBNR/25811484
4 | TI LMG2652 product page | HV GaN: 650 V, 140 mΩ, integrated driver+sense, bottom-cooled | https://www.ti.com/product/LMG2652
5 | DigiKey LMG2652RFBR | Availability / 12-week lead, 19-VQFN 8x6 mm | https://www.digikey.com/en/products/detail/texas-instruments/LMG2652RFBR/26251057
6 | LCSC CID12N65D (Tokmas) | All-LCSC HV fallback, 650 V, from $0.6276 | https://www.lcsc.com/product-detail/C21547657.html
7 | Farnell B65815E0000R049 | RM12 N49 core, UK source | https://uk.farnell.com/epcos/b65815e0000r049/transformer-core-rm-n49-57mm/dp/4167325
8 | TME B65815E0000R049 | A_L 3700 nH, Ae 146 mm^2, sold as pair | https://www.tme.eu/en/details/b65815e0000r049/ferrite-cores/epcos/
9 | TDK RM12 datasheet | A_L by grade (N49 = 3700 nH +30/-20%) | https://www.tdk-electronics.tdk.com/inf/80/db/fer/rm_12.pdf
10 | RM Cybernetics | UK Litz wire (12 A / 3 A variants) | https://www.rmcybernetics.com/
11 | OwnTech SPIN | Controller: STM32G4, HRTIM PWM, ADC 0-2.048 V | https://www.owntech.org/spin-2/
12 | OwnTech ADC docs | ADC input range 0-2.048 V, PWM-triggered sampling | https://docs.owntech.org/latest/examples/SPIN/ADC/adc_hrtim_trigger/
13 | LibreSolar BMS C1 | 60 V max -> sets 14S Na-ion upper limit | https://github.com/LibreSolar/bms-c1
14 | PCBway online quote | PCB fabrication cost calculator | https://www.pcbway.com/orderonline.aspx

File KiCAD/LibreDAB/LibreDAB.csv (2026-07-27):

Reference | Qty | Value | DNP | Exclude from BOM | Exclude from Board | Datasheet | Manufacturer | LCSC | Description
C1,C3,C7,C9,C11 | 5 | 4.7uF 50V X7S 0805 |  |  |  | https://wmsc.lcsc.com/wmsc/upload/file/pdf/v2/lcsc/2308111526_Murata-Electronics-GRT21BC71H475KE13L_C3861036.pdf | muRata(村田) | C3861036 | GRT21BC71H475KE13L
C2,C12 | 2 | 100nF 250V X7R 0805 |  |  |  | https://wmsc.lcsc.com/wmsc/upload/file/pdf/v2/lcsc/2211281000_YAGEO-CC0805KKX7RYBB104_C5182461.pdf | YAGEO(国巨) | C5182461 | CC0805KKX7RYBB104
C4 | 1 | 47uF, 80 V |  |  |  | https://wmsc.lcsc.com/wmsc/upload/file/pdf/v2/lcsc/2208301730_Lelon-HBV470M1KTR-1010_C3031594.pdf | Lelon(立隆) | C3031594 | HBV470M1KTR-1010
C5,C6 | 2 | 1nF (102) ±10% 50V |  |  |  | https://www.lcsc.com/datasheet/lcsc_datasheet_2304140030_Samsung-Electro-Mechanics-CL21B102KBCNNNC_C46653.pdf | SAMSUNG(三星) | C46653 | 1nF (102) ±10% 50V
C8,C10 | 2 | 20pF 50V C0G 0805 |  |  |  | https://www.lcsc.com/datasheet/lcsc_datasheet_2304140030_FH--Guangdong-Fenghua-Advanced-Tech-0805CG200F500NT_C176292.pdf | FH(风华) | C176292 | CAP CER 20pF 50V C0G 0805
D1 | 1 | TVS DIODE 60VWM 96.8VC SMB(DO-214AA) |  |  |  | https://www.lcsc.com/datasheet/C49066953.pdf | R+O(宏嘉诚) | C49066953 | SMBJ60A TVS
H1,H2,H3,H4 | 4 | MountingHole_Pad |  |  |  | ~ |  | C2916333 | Mounting Hole with connection
J1,J4,J5,J6 | 4 | HX PM2.54-1X4P TP H8.5-ZQ |  |  |  | https://www.lcsc.com/datasheet/lcsc_datasheet_2504301452_hanxia-HX-PM2-54-1x4P-TP-H8-5-ZQ_C48641754.pdf | hanxia(韩下) | C48641754 | HX PM2.54-1X4P TP H8.5-ZQ
J2,J3,J7,J8 | 4 | TS30050050-040 |  |  |  | None | XFCN(兴飞) | C51018168 | TS30050050-040
LOGO1 | 1 | N/A |  |  |  | N/A |  |  | Fairflow Energy Logo
Q1,Q2,Q3,Q4 | 4 | SP010N01BGHTO |  |  |  | https://wmsc.lcsc.com/wmsc/upload/file/pdf/v2/lcsc/2404191548_Siliup-SP010N01BGHTO_C22385350.pdf | Siliup(矽普) | C22385350 | SP010N01BGHTO
R1 | 1 | 47kΩ ±0.1% 125mW 0805 |  |  |  | https://wmsc.lcsc.com/wmsc/upload/file/pdf/v2/lcsc/2207251830_UNI-ROYAL-Uniroyal-Elec-TC0525B4702T5G_C2989281.pdf | UNI-ROYAL(厚声) | C2989281 | TC0525B4702T5G
R2 | 1 | 12.1kΩ_±0.1%_125mW_0805 |  |  |  | https://www.lcsc.com/datasheet/C1509644.pdf | Viking | C1509644 | ARG05BTC1212N
R3 | 1 | 1MΩ (1004) ±1% |  |  |  | https://www.lcsc.com/datasheet/lcsc_datasheet_2206010200_UNI-ROYAL-Uniroyal-Elec-0805W8F1004T5E_C17514.pdf | UNI-ROYAL(厚声) | C17514 | 1MΩ (1004) ±1%
R4 | 1 | 25.5KΩ (2552) ±1% |  |  |  | https://www.lcsc.com/datasheet/lcsc_datasheet_2206010000_UNI-ROYAL-Uniroyal-Elec-0805W8F2552T5E_C46670.pdf | UNI-ROYAL(厚声) | C46670 | 25.5KΩ (2552) ±1%
R5 | 1 | 0.5mΩ ±1% 3W 2512 |  |  |  | https://wmsc.lcsc.com/wmsc/upload/file/pdf/v2/lcsc/2304140030_TA-I-Tech-RLM25FEGMR50M_C710260.pdf | 大毅科技 | C710260 | RLM25FEGMR50M
R6,R7 | 2 | 10kΩ ±0.1% 125mW 0805 |  |  |  | https://wmsc.lcsc.com/wmsc/upload/file/pdf/v2/lcsc/2307211812_UNI-ROYAL-Uniroyal-Elec-TC0525B1002T5G_C7431042.pdf | UNI-ROYAL(厚声) | C7431042 | TC0525B1002T5G
R8,R9,R14,R15 | 4 | 3.3Ω ±5% 1W 2512 |  |  |  | https://www.lcsc.com/datasheet/C55115149.pdf | HWA CHN | C55115149 | HRC2512J3R3 LNTN
R10,R11,R16,R17 | 4 | 10kΩ ±1% 0805 |  |  |  | https://wmsc.lcsc.com/wmsc/upload/file/pdf/v2/lcsc/2308241947_FOJAN-FRC0805F1002TS_C2907219.pdf | FOJAN(富捷) | C2907219 | FRC0805F1002TS
R12,R13 | 2 | 330kΩ ±0.1% 125mW 0805 |  |  |  | https://wmsc.lcsc.com/wmsc/upload/file/pdf/v2/lcsc/2311211102_YAGEO-RT0805BRD07330KL_C865408.pdf | YAGEO(国巨) | C865408 | RT0805BRD07330KL
TP1,TP2,TP3,TP4,TP5,TP6,TP7,TP8,TP9,TP10,TP11,TP12,TP13,TP14,TP15,TP16,TP17,TP18,TP19,TP20,TP21 | 21 | TestPoint_Probe |  |  |  | ~ |  |  | test point (alternative probe-style design)
U1,U5 | 2 | UCC27211DDAR |  |  |  | https://www.lcsc.com/datasheet/lcsc_datasheet_1808280155_Texas-Instruments-UCC27211DDAR_C141980.pdf | TI(德州仪器) | C141980 | UCC27211DDAR
U2,U3,U4 | 3 | 10 MHz Opamp |  |  |  | https://www.lcsc.com/datasheet/lcsc_datasheet_1912111437_Texas-Instruments-TLV9061IDBVR_C398358.pdf | TI(德州仪器) | C398358 | TLV9061IDBVR

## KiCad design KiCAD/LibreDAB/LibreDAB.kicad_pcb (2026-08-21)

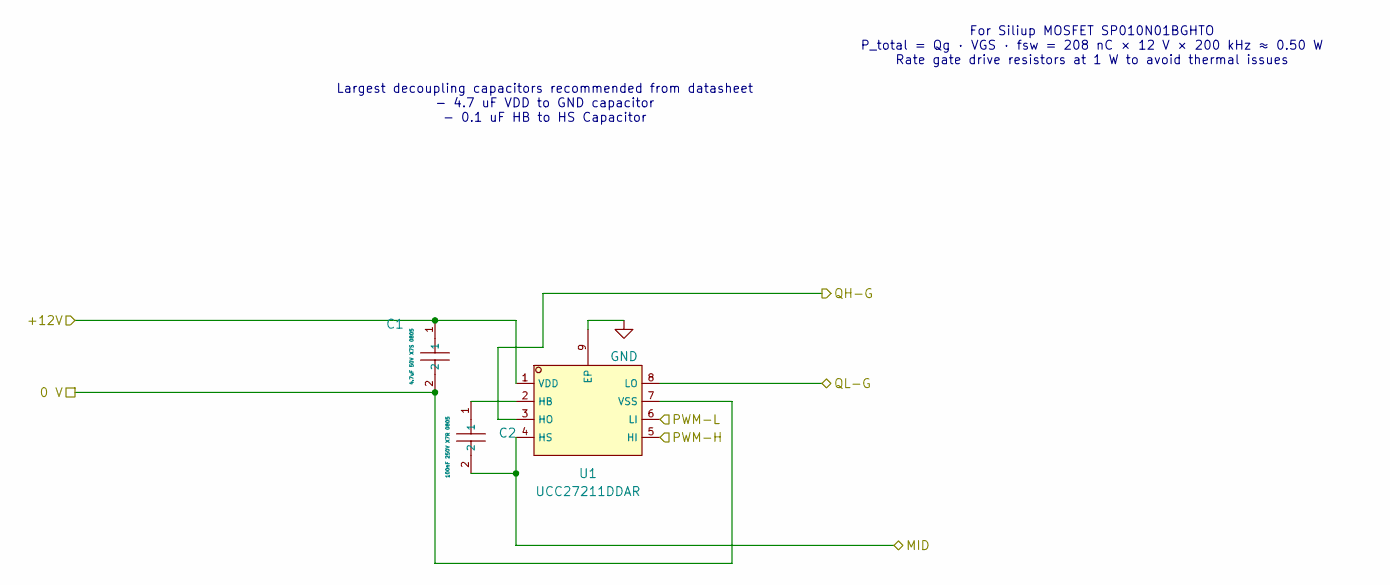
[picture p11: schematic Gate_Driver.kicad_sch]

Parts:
C1: 4.7uF 50V X7S 0805; C3861036_C0805; LCSC C3861036
C2: 100nF 250V X7R 0805; C5182461_C0805; LCSC C5182461
U1: UCC27211DDAR; C141980_SOIC-8_L4_9-W3_9-P1_27-LS6_0-BL-EP; LCSC C141980

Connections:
+12V: C1.1, U1.1 (VDD); also elsewhere on the board
/LV_Bridge/HO1: U1.3 (HO); also elsewhere on the board
/LV_Bridge/LO1: U1.8 (LO); also elsewhere on the board
/LV_Bridge/LSW1: C2.2, U1.4 (HS); also elsewhere on the board
/LV_Bridge/PWM-H1: U1.5 (HI); also elsewhere on the board
/LV_Bridge/PWM-L1: U1.6 (LI); also elsewhere on the board
GND: C1.2, U1.7 (VSS), U1.9 (EP); also elsewhere on the board
unnamed: C2.1, U1.2 (HB)

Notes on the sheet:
Largest decoupling capacitors recommended from datasheet - 4.7 uF VDD to GND capacitor - 0.1 uF HB to HS Capacitor
For Siliup MOSFET SP010N01BGHTO P_total = Qg · VGS · fsw = 208 nC × 12 V × 200 kHz ≈ 0.50 W Rate gate drive resistors at 1 W to avoid thermal issues

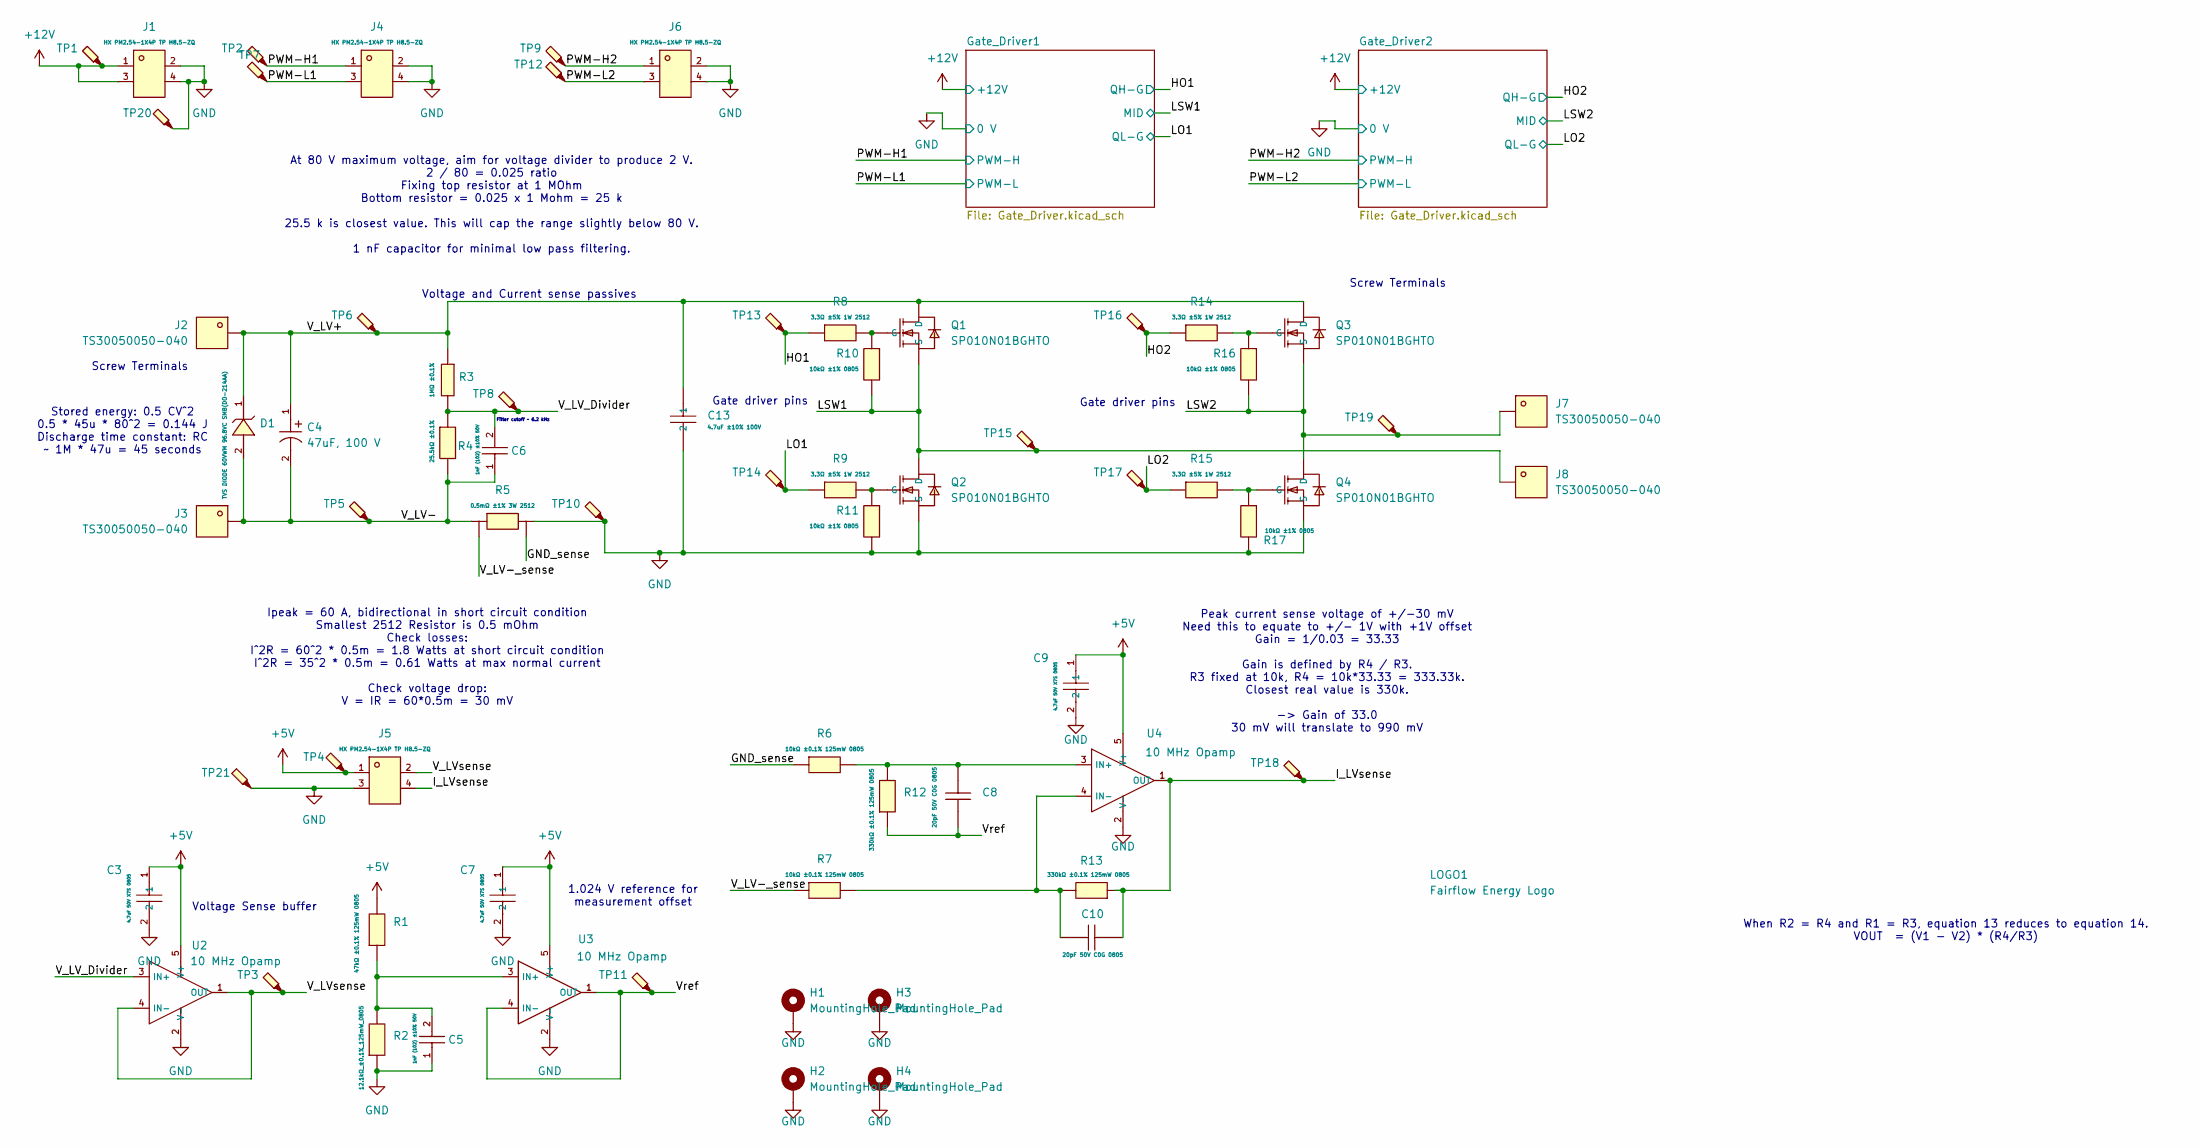
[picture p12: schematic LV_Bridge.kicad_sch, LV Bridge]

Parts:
C3, C7, C9: 4.7uF 50V X7S 0805; C3861036_C0805; LCSC C3861036
C4: 47uF, 100 V; C3031594_CAP-SMD_BD10_0-L10_3-W10_3-FD; LCSC C54525311
C5, C6: 1nF (102) ±10% 50V; C46653_C0805; LCSC C46653
C8, C10: 20pF 50V C0G 0805; C176292_C0805; LCSC C176292
C13: 4.7uF ±10% 100V; C41582415_C1206; LCSC C41582415
D1: TVS DIODE 60VWM 96.8VC SMB(DO-214AA); C49066953_SMB_L4_5-W3_7-LS5_4-RD; LCSC C49066953
H1, H2, H3, H4: MountingHole_Pad; MountingHole_4.3mm_M4_DIN965_Pad; LCSC C2916333
J1, J4, J5, J6: HX PM2.54-1X4P TP H8.5-ZQ; C48641754_HDR-SMD_4P-P2_54-V-F-LS4_7-R1; LCSC C48641754
J2, J3, J7, J8: TS30050050-040; C51018168_SMD_L5_0-W5_0_CON1_5X5_SMD; LCSC C51018168
LOGO1: N/A; FFE_Logo_12x12mm_Silk
Q1, Q2, Q3, Q4: SP010N01BGHTO; C22385350_TOLL-8_L10_4-W9_9-P1_20-LS11_7-BL_2; LCSC C22385350
R1: 47kΩ ±0.1% 125mW 0805; C2989281_R0805; LCSC C2989281
R2: 12.1kΩ_±0.1%_125mW_0805; C2989281_R0805; LCSC C1509644
R3: 1MΩ ±0.1%; C309662_R1206; LCSC C309662
R4: 25.5kΩ ±0.1%; C865332_R0805; LCSC C865332
R5: 0.5mΩ ±1% 3W 2512; C710260_RES-SMD_L6_4-W3_2_RLM25; LCSC C710260
R6, R7: 10kΩ ±0.1% 125mW 0805; C7431042_R0805; LCSC C7431042
R8, R9, R14, R15: 3.3Ω ±5% 1W 2512; C393074_RES-SMD_L6_4-W3_2-1; LCSC C55115149
R10, R11, R16, R17: 10kΩ ±1% 0805; C2907219_R0805; LCSC C2907219
R12, R13: 330kΩ ±0.1% 125mW 0805; C865408_R0805; LCSC C865408
TP1, TP2, TP3, TP4, TP5, TP6, TP7, TP8, TP9, TP10, TP11, TP12, TP13, TP14, TP15, TP16, TP17, TP18, TP19, TP20, TP21: TestPoint_Probe; TestPoint_Pad_D1.0mm
U2, U3, U4: 10 MHz Opamp; C398358_SOT-23-5_L3_0-W1_7-P0_95-LS2_8-BL; LCSC C398358

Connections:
+5V: C3.1, C7.1, C9.1, J5.1, R1.2, TP4.1, U2.5 (V+), U3.5 (V+), U4.5 (V+)
+12V: J1.1, J1.3, TP1.1; also elsewhere on the board
/LV_Bridge/GND_sense: R5.4 (Vsense2), R6.1
/LV_Bridge/HO1: R8.1, TP13.1; also elsewhere on the board
/LV_Bridge/HO2: R14.1, TP16.1; also elsewhere on the board
/LV_Bridge/I_LVsense: C10.2, J5.4, R13.1, TP18.1, U4.1 (OUT)
/LV_Bridge/LO1: R9.1, TP14.1; also elsewhere on the board
/LV_Bridge/LO2: R15.1, TP17.1; also elsewhere on the board
/LV_Bridge/LSW1: J8.1, Q1.2 (S), Q2.3 (D), R10.2, TP15.1; also elsewhere on the board
/LV_Bridge/LSW2: J7.1, Q3.2 (S), Q4.3 (D), R16.2, TP19.1; also elsewhere on the board
/LV_Bridge/PWM-H1: J4.1, TP2.1; also elsewhere on the board
/LV_Bridge/PWM-H2: J6.1, TP9.1; also elsewhere on the board
/LV_Bridge/PWM-L1: J4.3, TP7.1; also elsewhere on the board
/LV_Bridge/PWM-L2: J6.3, TP12.1; also elsewhere on the board
/LV_Bridge/V_LV+: C4.1, C13.1, D1.1 (K), J2.1, Q1.3 (D), Q3.3 (D), R3.1, TP6.1
/LV_Bridge/V_LV-: C4.2, C6.1, D1.2 (A), J3.1, R4.2, R5.1, TP5.1
/LV_Bridge/V_LV-_sense: R5.3 (Vsense1), R7.1
/LV_Bridge/V_LV_Divider: C6.2, R3.2, R4.1, TP8.1, U2.3 (IN+)
/LV_Bridge/V_LVsense: J5.2, TP3.1, U2.1 (OUT), U2.4 (IN-)
/LV_Bridge/Vref: C8.2, R12.1, TP11.1, U3.1 (OUT), U3.4 (IN-)
GND: C3.2, C5.1, C7.2, C9.2, C13.2, H1.1, H2.1, H3.1, H4.1, J1.2, J1.4, J4.2, J4.4, J5.3, J6.2, J6.4, Q2.2 (S), Q4.2 (S), R2.1, R5.2, R11.2, R17.2, TP10.1, TP20.1, TP21.1, U2.2 (V-), U3.2 (V-), U4.2 (V-); also elsewhere on the board
unnamed: Q1.1 (G), R8.2, R10.1
unnamed: Q2.1 (G), R9.2, R11.1
unnamed: Q3.1 (G), R14.2, R16.1
unnamed: Q4.1 (G), R15.2, R17.1
unnamed: C5.2, R1.1, R2.2, U3.3 (IN+)
unnamed: C8.1, R6.2, R12.2, U4.3 (IN+)
unnamed: C10.1, R7.2, R13.2, U4.4 (IN-)

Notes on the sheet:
Gate driver pins
At 80 V maximum voltage, aim for voltage divider to produce 2 V. 2 / 80 = 0.025 ratio Fixing top resistor at 1 MOhm Bottom resistor = 0.025 x 1 Mohm = 25 k 25.5 k is closest value. This will cap the range slightly below 80 V. 1 nF capacitor for minimal low pass filtering.
Screw Terminals
Stored energy: 0.5 CV^2 0.5 * 45u * 80^2 = 0.144 J Discharge time constant: RC ~ 1M * 47u = 45 seconds
Voltage Sense buffer
1.024 V reference for measurement offset
When R2 = R4 and R1 = R3, equation 13 reduces to equation 14. VOUT = (V1 - V2) * (R4/R3)
Peak current sense voltage of +/-30 mV Need this to equate to +/- 1V with +1V offset Gain = 1/0.03 = 33.33 Gain is defined by R4 / R3. R3 fixed at 10k, R4 = 10k*33.33 = 333.33k. Closest real value is 330k. -> Gain of 33.0 30 mV will translate to 990 mV
Ipeak = 60 A, bidirectional in short circuit condition Smallest 2512 Resistor is 0.5 mOhm Check losses: I^2R = 60^2 * 0.5m = 1.8 Watts at short circuit condition I^2R = 35^2 * 0.5m = 0.61 Watts at max normal current Check voltage drop: V = IR = 60*0.5m = 30 mV
Voltage and Current sense passives
Filter cutoff ~ 6.2 kHz

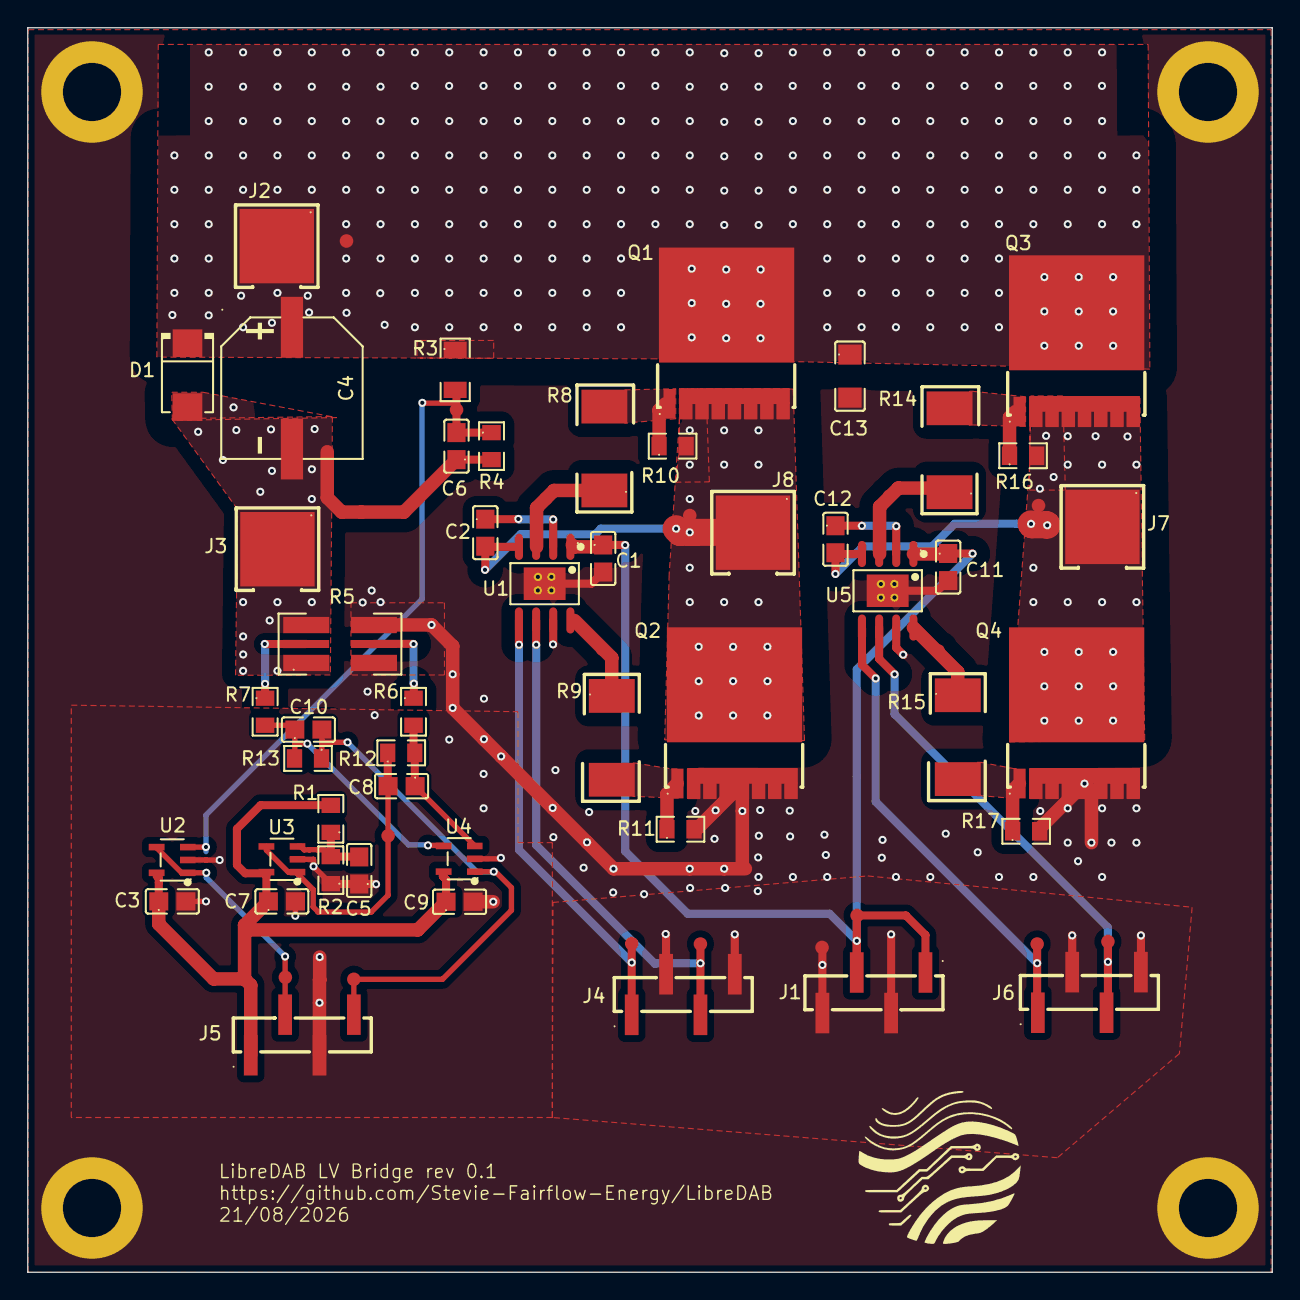
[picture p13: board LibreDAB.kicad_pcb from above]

Board: 4 copper layers, 92.0 x 92.0 mm, 74 parts (0 on the bottom side), 30 nets.

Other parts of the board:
C11: 4.7uF 50V X7S 0805; C3861036_C0805
C12: 100nF 250V X7R 0805; C5182461_C0805
U5: UCC27211DDAR; C141980_SOIC-8_L4_9-W3_9-P1_27-LS6_0-BL-EP

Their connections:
+12V: C11.1, U5.1 (VDD); also elsewhere on the board
/LV_Bridge/HO2: U5.3 (HO); also elsewhere on the board
/LV_Bridge/LO2: U5.8 (LO); also elsewhere on the board
/LV_Bridge/LSW2: C12.2, U5.4 (HS); also elsewhere on the board
/LV_Bridge/PWM-H2: U5.5 (HI); also elsewhere on the board
/LV_Bridge/PWM-L2: U5.6 (LI); also elsewhere on the board
GND: C11.2, U5.7 (VSS), U5.9 (EP); also elsewhere on the board
unnamed: C12.1, U5.2 (HB)

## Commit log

2026-06-09 Added draft design notes
    Draft design notes using EPC and TI half bridge drivers, and a custom RM12 transformer
    [20260609 LibreDAB_planning_pack.xlsx, DAB from scaling laws calcs.ods]
2026-06-09 uVerter copy as KiCad starting point
    [20260609 LibreDAB_planning_pack.xlsx, AC_voltage_sense.kicad_sch, Common_mode.kicad_sch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]
2026-06-09 Initial kicad schematic draft
    [20260609 LibreDAB_planning_pack.xlsx, DC_HV_voltage_sense.kicad_sch, LibreDAB.kicad_sch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]
2026-06-10 Schematic updates still setting up
    [20260609 LibreDAB_planning_pack.xlsx, current.kicad_sch, feeder.kicad_sch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]
2026-07-07 Started LibreDAB KiCAD files from scratch
    [AC_voltage_sense.kicad_sch, Common_mode.kicad_sch, DC_HV_voltage_sense.kicad_sch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]
2026-07-07 Setup blank LibreDAB KiCad project
    [LibreDAB.kicad_pcb, LibreDAB.kicad_sch]
2026-07-07 Added a LV bridge prototype module schematic
    [LibreDAB.kicad_sch]
2026-07-07 Minor updates to LV switching module
2026-07-09 Added most footprints from LCSC import
    [LibreDAB.kicad_sch]
2026-07-09 PCB component placement continues
    [LibreDAB.kicad_pcb, LibreDAB.kicad_sch]
2026-07-13 Added WIP Gate Driver
    [Aux_Power_Supplies.kicad_sch, Gate_Driver.kicad_sch, HV_Bridge.kicad_sch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]
2026-07-13 Added more gate drive schematic info
    [Gate_Driver.kicad_sch, LV_Bridge.kicad_sch]
2026-07-20 Gate Drive schematic and footprints added
    This is the last commit before trying the combined gate drive and sensing on the power board.
    [Gate_Driver.kicad_sch, LV_Bridge.kicad_sch, LibreDAB.kicad_pcb]
2026-07-20 Edits to gate drive circuitry
    [Gate_Driver.kicad_sch, LV_Bridge.kicad_sch, LibreDAB.kicad_pcb]
2026-07-21 Tidied symbols
    [Gate_Driver.kicad_sch, LV_Bridge.kicad_sch]
2026-07-21 Minor edits
    [LV_Bridge.kicad_sch]
2026-07-22 Added multi-pad current sense resistor footprint
    [LV_Bridge.kicad_sch, LibreDAB.kicad_pcb]
2026-07-22 Added all major components to LV board
    [LV_Bridge.kicad_sch, LibreDAB.kicad_pcb]
2026-07-23 LV Stage schematic ready for tidying and layout
    [LV_Bridge.kicad_sch]
2026-07-23 Annotation numbers reset
    [Gate_Driver.kicad_sch, LV_Bridge.kicad_sch]
2026-07-23 PCB component placement on 92 x 92 mm board
    [Gate_Driver.kicad_sch, LibreDAB.csv, LibreDAB.kicad_pcb]
2026-07-24 Added JLCPCB design rules
    From: https://github.com/Cimos/KiCad-CustomDesignRules
2026-07-24 Edited default rules to match use case
2026-07-24 Initial routing complete
    [LV_Bridge.kicad_sch, LibreDAB.kicad_pcb]
2026-07-24 Started laying out power routing zones
    [LibreDAB.kicad_pcb]
2026-07-27 PCB updates, getting ready for review
    [LibreDAB.kicad_pcb, VIA calculations.ods]
2026-07-27 Resolved various DRC issues. Almost ready for review
    [LV_Bridge.kicad_sch, LibreDAB.kicad_pcb]
2026-07-27 Minor edits getting ready for review
    [LibreDAB.kicad_pcb]
2026-07-27 Ready for LV Bridge review
    [LV_Bride_Rev_0.1_bom.csv, LV_Bride_Rev_0.1_designators.csv, LV_Bride_Rev_0.1_positions.csv]
2026-07-27 pdf of schematic added
    [LV_Bridge.kicad_sch]
2026-07-27 Tidying for review
    [LibreDAB.csv]
2026-08-21 Added 100 V DC link capacitors to schematic
2026-08-21 Added 100 V capacitors to PCB layout
    [LibreDAB.kicad_pcb]
2026-08-21 Updated Voltage divider to 1206 for top half and 0.1%
    [LV_Bridge.kicad_sch, LibreDAB.kicad_pcb]
2026-08-21 Review comments addressed or parked
    [LV_Bridge.kicad_sch, LibreDAB.kicad_pcb]
2026-08-21 Updated production files using production toolkit
    [LV_Bride_Rev_0.1_bom.csv, LV_Bride_Rev_0.1_designators.csv, LV_Bride_Rev_0.1_positions.csv]
